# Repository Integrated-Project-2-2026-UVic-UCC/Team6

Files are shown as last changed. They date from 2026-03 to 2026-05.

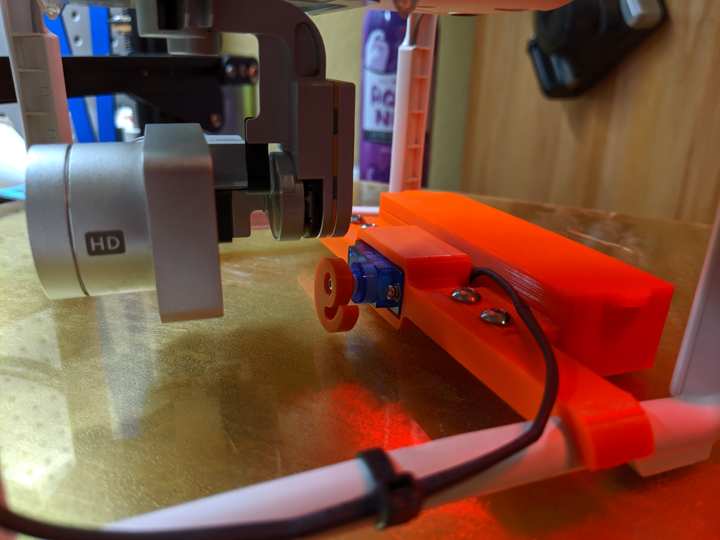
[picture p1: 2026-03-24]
Mechanical Components/Internet designs/IMG_20191102_212928.jpg

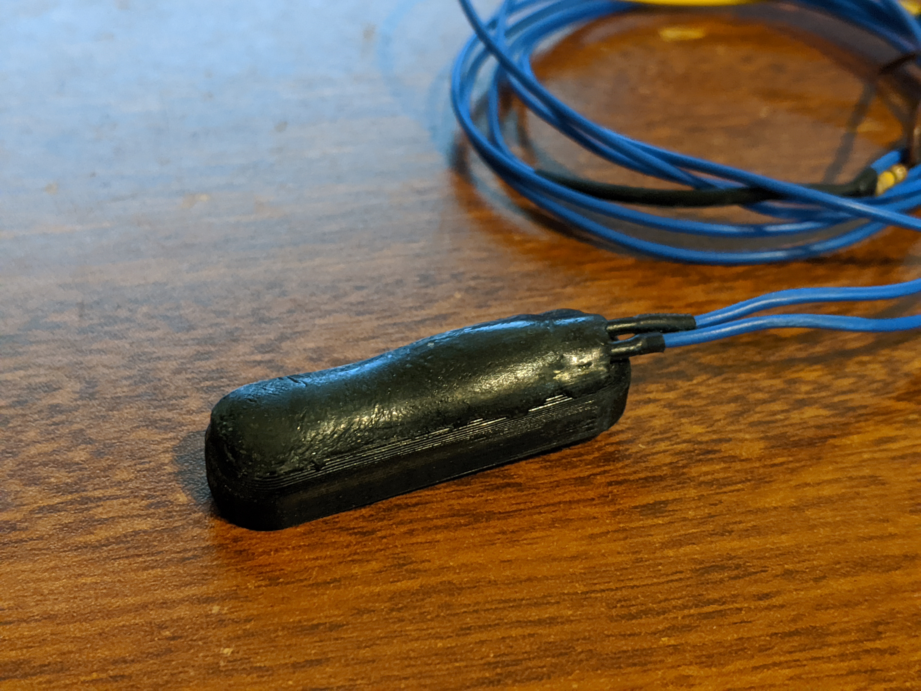
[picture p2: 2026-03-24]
Mechanical Components/Internet designs/IMG_20191102_212803.jpg

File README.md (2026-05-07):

## 1. Project Overview
This project focuses on the design, development, and integration of a remote-controlled attachable hook and pulley system for drones. The primary application is to facilitate automated and safe cable routing in environments where manual deployment is hazardous, inefficient, or physically restricted.

## 2. Objectives
The project is driven by a clear set of technical and operational goals:

### 2.1 Main Objective
To design and assemble a fully functional, remote-controlled hook attachment for drone-assisted cable deployment.

### 2.2 Specific Objectives
* **Pulley System:** Develop a reliable mechanism for cable management and tension control.
* **Safety Features:** Integrate hardware and software failsafes to ensure secure operations.
* **RF Communication:** Establish a robust Radio Frequency link for long-range control.
* **Validation:** Conduct rigorous testing to optimize performance and payload stability.

## 3. Team Organization and Methodology
The project follows a structured multidisciplinary model managed under the Scrum Framework.

### 3.1 Roles and Responsibilities
* **Project Leader:** Jan Font
* **Mechanical Manager:** Martí Alsina
* **Electrical Manager:** Oriol Bonet
* **Software Manager:** Xavier Vilalta

### 3.2 Professional Values (Scrum)
Our team operates under the core values of Courage to face technical challenges, Focus on sprint goals, Commitment to the project's success, Respect for individual expertise, and Openness regarding development obstacles.

## 4. Technical Architecture and Progress
The system is divided into three fundamental engineering pillars. Below is the progress achieved to date:

### 4.1 Mechanical tasks
* **Claw and Pulley Design:** Developed functional 3D designs for the mechanical gripping system.
* **Prototyping & Assembly:** Successful manufacturing and assembly of the first fully operational physical prototype.
* **Component Housings (Current Task):** Currently redesigning a larger protective enclosure (housing) to better accommodate all onboard drone electronics. Additionally, a dedicated, ergonomic casing for the remote control is being developed.

### 4.2 Electrical and Software tasks
* **RF Setup:** Established a stable communication link between the Transmitter (Command) and the Receiver.
* **System Logic:** Implementation of the electrical diagram, managing 5V output controls for motor drivers.
* **Power Management:** Integration of the battery and receiver units within the system logic.
* **Software Finalization:** The final control software (including motor control, safety limits, and communication protocols) is fully integrated and operational.

## 5. Project Roadmap and Current Status
The project has successfully transitioned into the real-world testing and iterative improvement phase. The first full prototype has been assembled and successfully flight-tested with the drone, with all systems functioning correctly. The current focus is on upgrading the physical enclosures for both the drone module and the remote control.

### 5.1 Achievements to Date
* Successful assembly of the first functional prototype.
* **Successful real-world flight testing with the drone**, confirming system reliability, payload stability, and the correct operation of all mechanical and electrical features.
* Final software logic is highly advanced and fully operational.
* Validation of the electrical control circuit and safety mechanisms.

### 5.2 Challenges Addressed (Job Stoppers)
* **LoRa Modules:** Overcame initial problems regarding establishing stable communication with the modules.
* **Procurement:** Managed minor delays in the component supply chain.

### 5.3 Next Steps
* Finalize and manufacture the redesigned, larger housing for the drone accessory to ensure an optimal and secure fit for all electronic components.
* Design, 3D print, and assemble the custom casing for the remote control.
* Identify final performance metrics and apply continuous technical improvements based on the recent flight testing feedback.

## 6. References
* Madsen, M. (2018). *DJI Phantom 3 – Payload Dropper v2*.
* Drone Sky Hook. *Dual Release and Drop PLUS for DJI Phantom 3*.
* 3Deddy. (2019). *DJI Phantom 3 – Payload Dropper*.

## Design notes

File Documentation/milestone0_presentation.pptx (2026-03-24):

## Milestone 0: Presentation

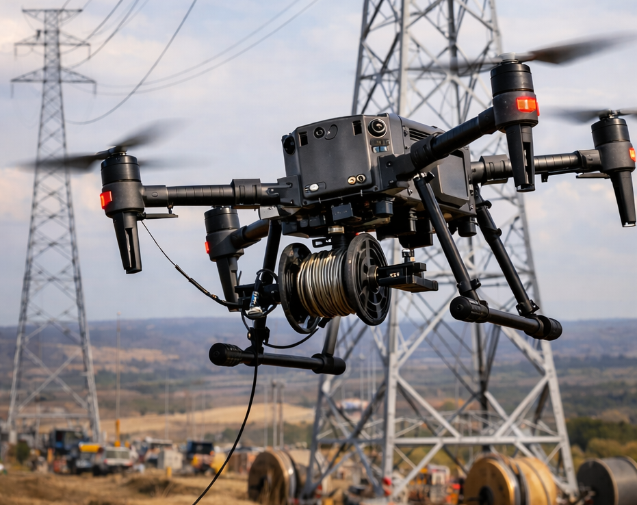
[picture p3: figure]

Oriol Bonet, Martí Alsina, Xavier Vilalta and Jan Font
Integrated Project II
Universitat de Vic

## PROJECT PROPOSAL

- Attachable hook for a drone
- Cable Routing
- Remote controlled

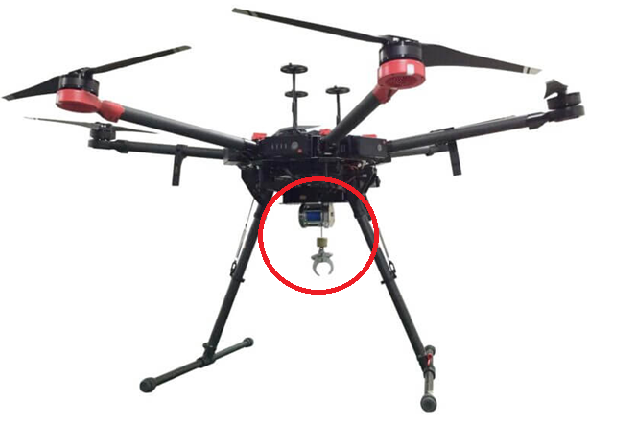
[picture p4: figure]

## OBJECTIVES

- Main objective
  - Assembly of a remote-controlled hook attachment
- Specific objectives
  - Pulley system
  - Safety features

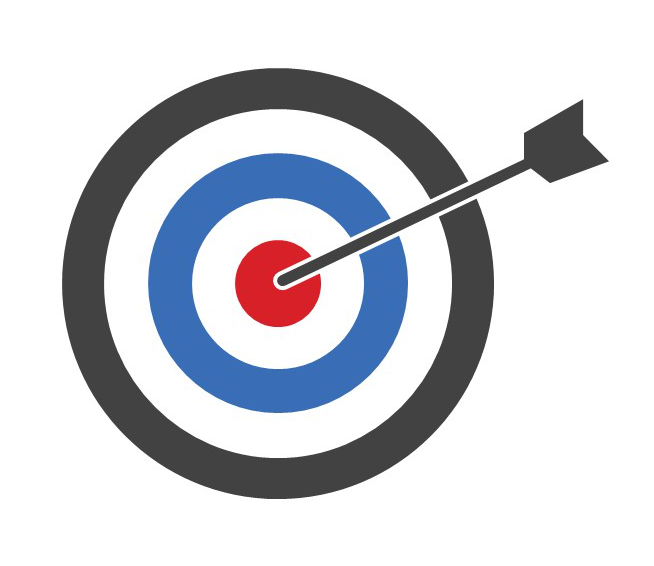
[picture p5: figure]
Simple Objective Slide Template for PowerPoint

## TEAM ORGANITZATION

- Project leader → Jan Font
- Mechanical manager → Martí Alsina
- Electrical manager → Oriol Bonet
- Software manager → Xavier Vilalta

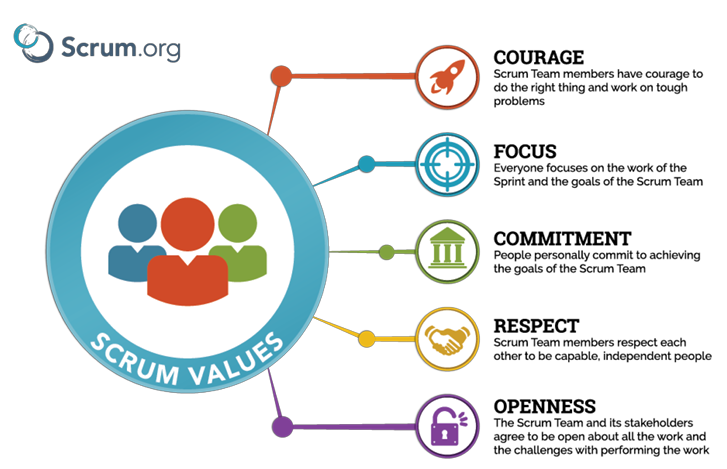
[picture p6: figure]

## MANAGEMENT PLANNING

Project leader
Mechanical manager
Electrical manager
Software Manager
All members

- Weekly review
- Sprint Planning / Sprint Review

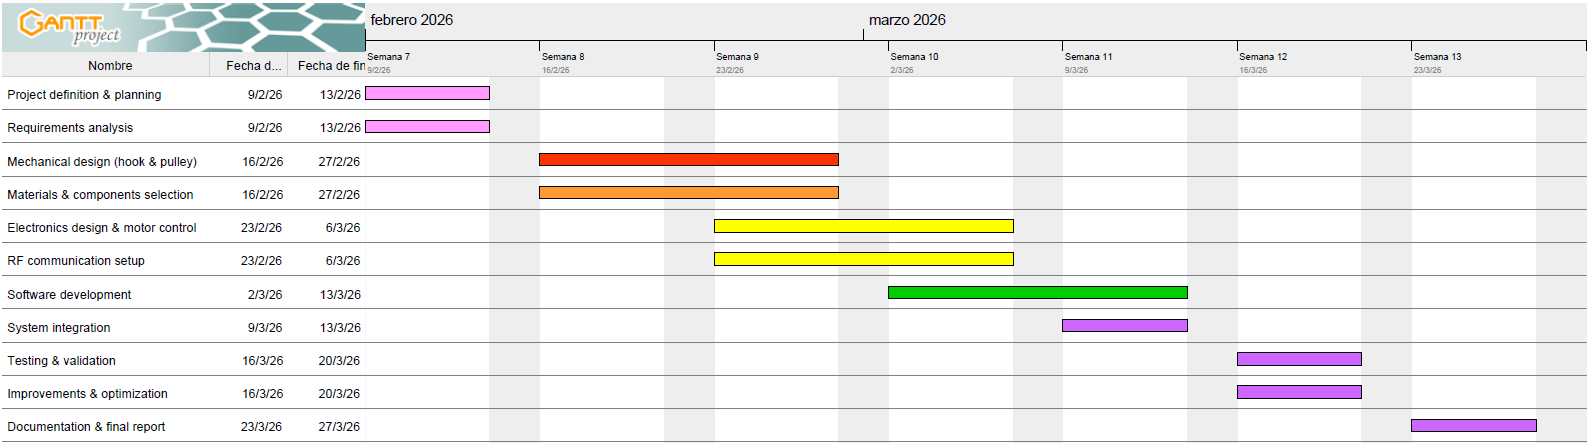
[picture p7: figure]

## WEBSITE

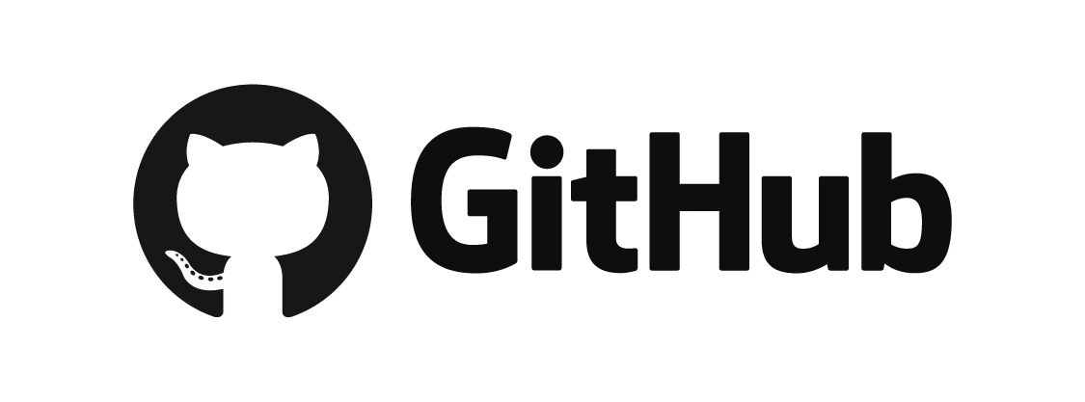
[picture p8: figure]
Unlocking the Power of GitHub: A Comprehensive Guide for Developers and Teams

- https://github.com/Integrated-Project-2-2026-UVic-UCC/Team6

## REFERENCES

- Madsen, M. (2018). DJI Phantom 3 – Payload Dropper v2. https://www.thingiverse.com/thing:2913421
- Drone Sky Hook. (n.d.). Dual Release and Drop PLUS for DJI Phantom 3. https://www.droneskyhook.com/product-page/Dual-Release-and-Drop-PLUS-for-DJI-Phantom-3
- 3Deddy. (2019). DJI Phantom 3 – Payload Dropper. https://www.thingiverse.com/thing:3953342

## Thank you for your attention!

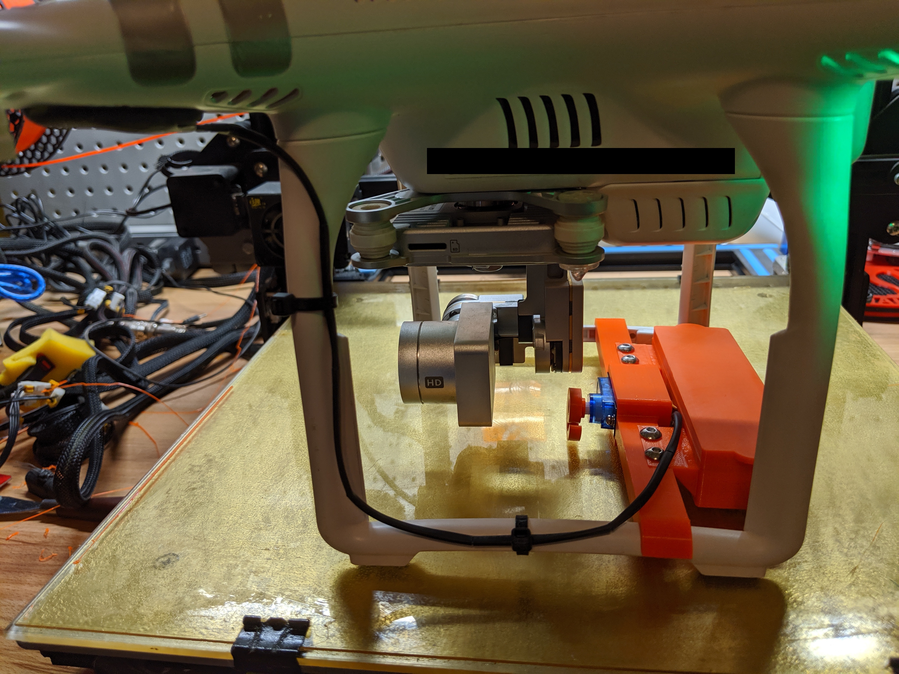
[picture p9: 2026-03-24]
Mechanical Components/Internet designs/Light_Cover.png

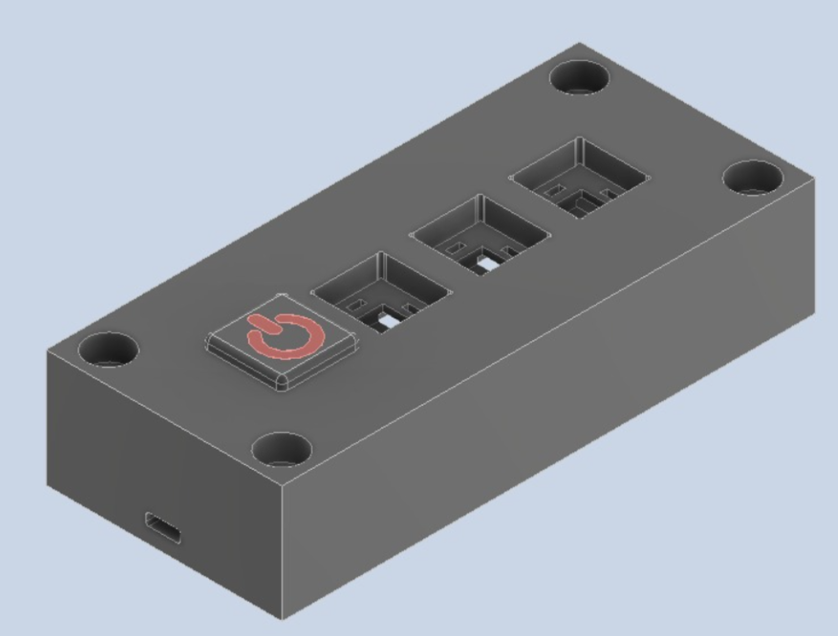
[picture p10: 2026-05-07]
Mechanical Components/Self made designs/Remote/Captura de pantalla 2026-05-07 155647.png

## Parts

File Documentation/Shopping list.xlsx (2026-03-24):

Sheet: Project Specifications
Micro Geared Motor
Angular Velocity [n] (rpm) | 35 | rpm
Angular Velocity [w] (rad/s) | 3.67 | rad/s
Nominal Power [W] | 0.25 | W
Roll radium r] | 5 | mm
Fmàx motor [F](N) | 13.64185227 | N
Max load [m](Kg) | 1.390606755 | Kg
Linial Velocity [v] | 0.01832595715 | m/s

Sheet: Shoping List
PRELIMINAR ORDER LIST
Team: | Group 6: Pulling cables
NAME | QUANTITY | LINK | PROVIDER | UNIT PRICE [€] | FINAL PRICE [€] | CURRENT COST [€] | AVAILABLE BUDGET [€]
Spiral cable | 1 | Cable (https://www.amazon.es/Espiral-Extensi%C3%B3n-Remolque-N%C3%BAcleos-Poliuretano/dp/B0BQGCTNV5) | Amazon | 32 € | 32 € | 207.37 € | 92.63 €
Batery | 1 | Batery (https://www.amazon.es/Recargable-4-8V-Juguetes-veh%C3%ADculos-Todoterreno/dp/B07Y9S5T6Z) | Amazon | 17 € | 17 €
Micro geared motor | 1 | Motor (https://www.amazon.es/Fasizi-35RPM-Metal-Motor-GA12-N20/dp/B09Z297R57) | Amazon | 10.99 € | 10.99
Fishing line | 1 | String (https://www.amazon.es/metros-transparente-monofilamento-alambre-tensi%C3%B3n/dp/B0BG2P8C16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) | Amazon | 5 € | 5
Magnetic sensor | 1 | Magnetic sensor (https://www.amazon.es/Interruptor-magn%C3%A9tico-Cilindro-neum%C3%A1tico-interruptor/dp/B08T6MTFHJ) | Amazon | 6.30 € | 6.3
Servomotor | 1 | Servo (https://www.amazon.es/Fasizi-unids-engranaje-anal%C3%B3gico-helic%C3%B3ptero/dp/B09Z28X9RL) | Amazon | 15.99 € | 15.99
Switch | 1 | Switch (https://www.amazon.es/SODIAL-250V-SPST-Interruptor-Basculante/dp/B00F4MG7HY) | Amazon | 3 € | 3
LoRa v3 | 1 | LoRa (https://www.amazon.es/Diymore-SX1262-Bluetooth-M%C3%B3dulos-Desarrollo/dp/B0DMDRY97S) | Amazon | 42.74 € | 42.74
Zip tie | 1 | Zip ties (https://www.amazon.es/AiQInu-Unidades-Bridas-Plastico-Peque%C3%B1as%EF%BC%8CBridas/dp/B0CSFKVPKQ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) | Amazon | 5.78 € | 5.78
Load sensor | 1 | Load sensor (https://www.amazon.es/dp/B0FPFWW4FL?aref=dMY6anLfPK&sp_csd=d2lkZ2V0TmFtZT1zcF9kZXRhaWw) | Amazon | 5.47 € | 5.47
Push buttons | 1 | Push buttons (https://www.amazon.es/DAOKAI-interruptor-moment%C3%A1neo-componentes-electr%C3%B3nicos/dp/B09WVFHMSV) | Amazon | 6.33 € | 6.33 €
LED lights | 1 | LED lights (https://www.amazon.es/Super-brillante-LEDs-Blanco-6000K/dp/B0784TDHVW) | Amazon | 7.65 € | 7.65 €
3D print wire | 1 | Print wire (https://www.amazon.es/ELEGOO-Filamento-Impresora-Dimensional-Impresoras/dp/B0F3BX78YW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) | Amazon | 13.21 | 13.21 €
Fuse Relay | 1 | https://www.amazon.es/TOOHUI-Soporte-Portafusibles-Standard-Impermeable/dp/B07KPKND2Q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 | Amazon | 12.98 | 12.98 €
Fuse Holder | 1 | https://www.amazon.es/AiQInu-Fusibles-12v-32v-Mediano-Autom%C3%B3vil/dp/B0F4CQXXV4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 | Amazon | 14.99 | 14.99 €
Relay | 1 | Relay (https://www.amazon.es/KY-019-disparador-Arduino-Raspberry-arduino/dp/B0CT39JT4P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) | Amazon | 7.94 | 7.94 €

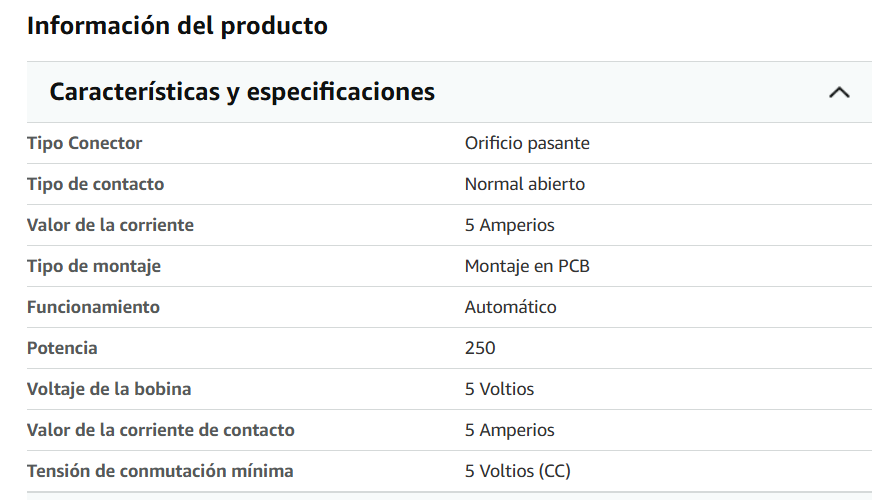
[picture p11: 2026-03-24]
Electronic Components/relay.png

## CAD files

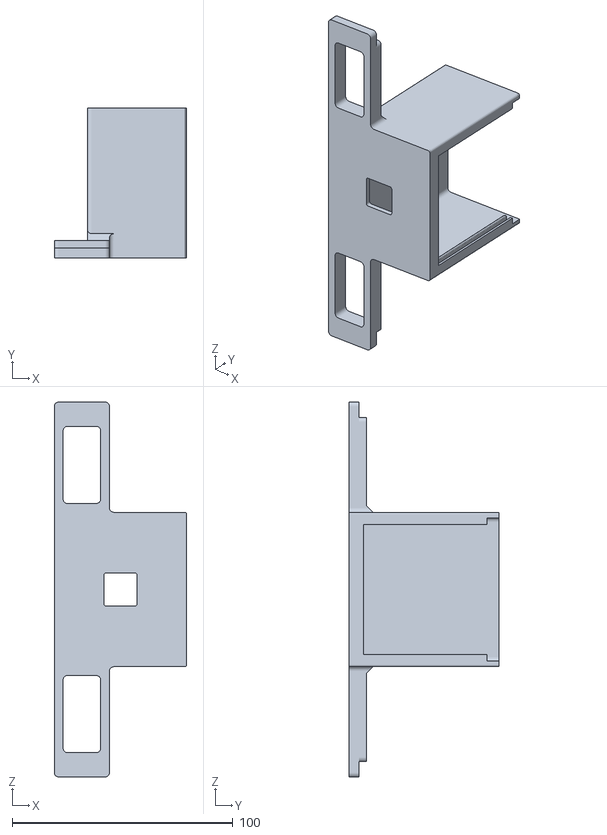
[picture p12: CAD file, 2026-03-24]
Mechanical Components/Self made designs/Components housing/Caixa_v2.stl
60.0 x 68.0 x 170.0

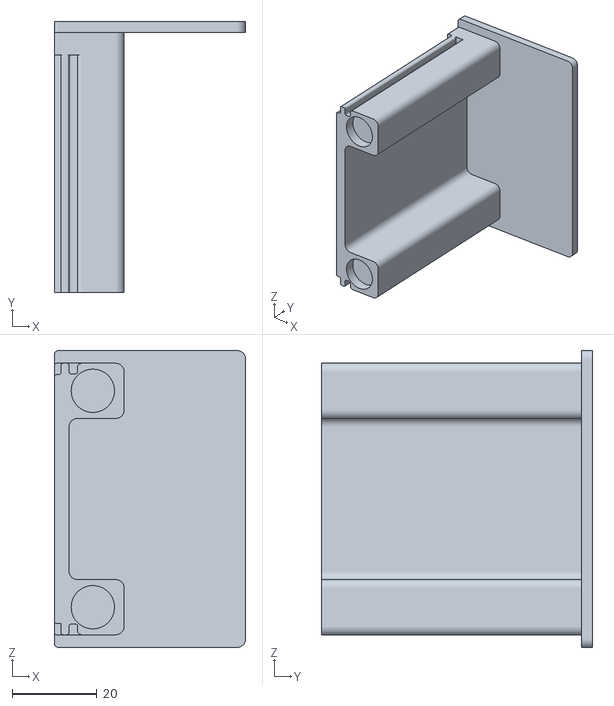
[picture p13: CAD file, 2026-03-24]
Mechanical Components/Self made designs/Components housing/tapa caixa.stl
45.1 x 63.8 x 70.0

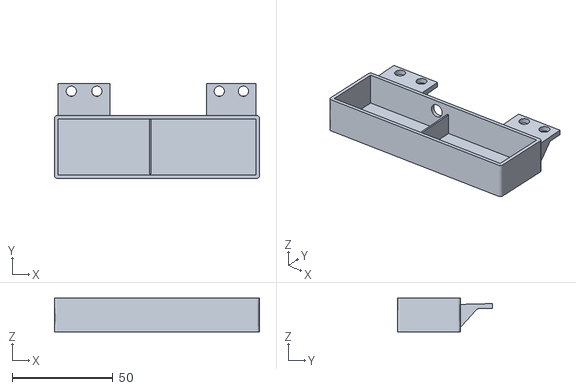
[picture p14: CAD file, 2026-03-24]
Mechanical Components/Internet designs/Light_Cover.stl
101.8 x 47.1 x 16.8

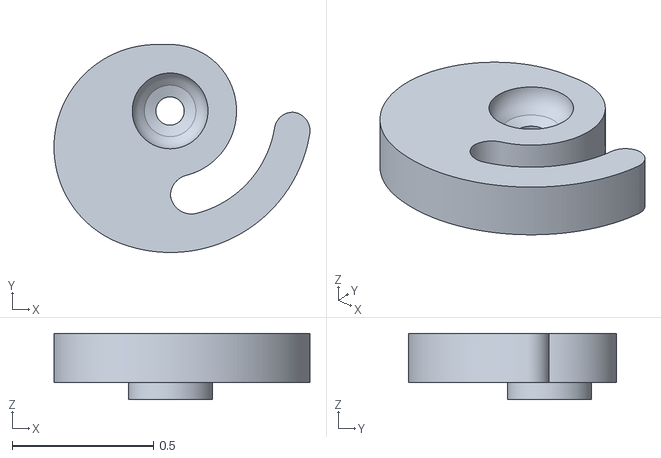
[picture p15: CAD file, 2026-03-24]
Mechanical Components/Internet designs/LOAD_BAR.stl
0.907 x 0.737 x 0.235

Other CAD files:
Mechanical Components/Internet designs/Servo_Connector_Gear.stl
Mechanical Components/Internet designs/MicroMotor_mount.STL
Mechanical Components/Internet designs/Base.stl
Mechanical Components/Internet designs/Connector_Gear.stl
Mechanical Components/Internet designs/Micro_gear01.STL
Mechanical Components/Internet designs/MicroMotor_mount_with_base.STL
Mechanical Components/Internet designs/Claw.stl
Mechanical Components/Internet designs/Micro_gear02.STL
Mechanical Components/Internet designs/Connector.stl

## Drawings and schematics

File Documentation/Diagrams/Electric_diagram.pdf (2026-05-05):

A1

-S3

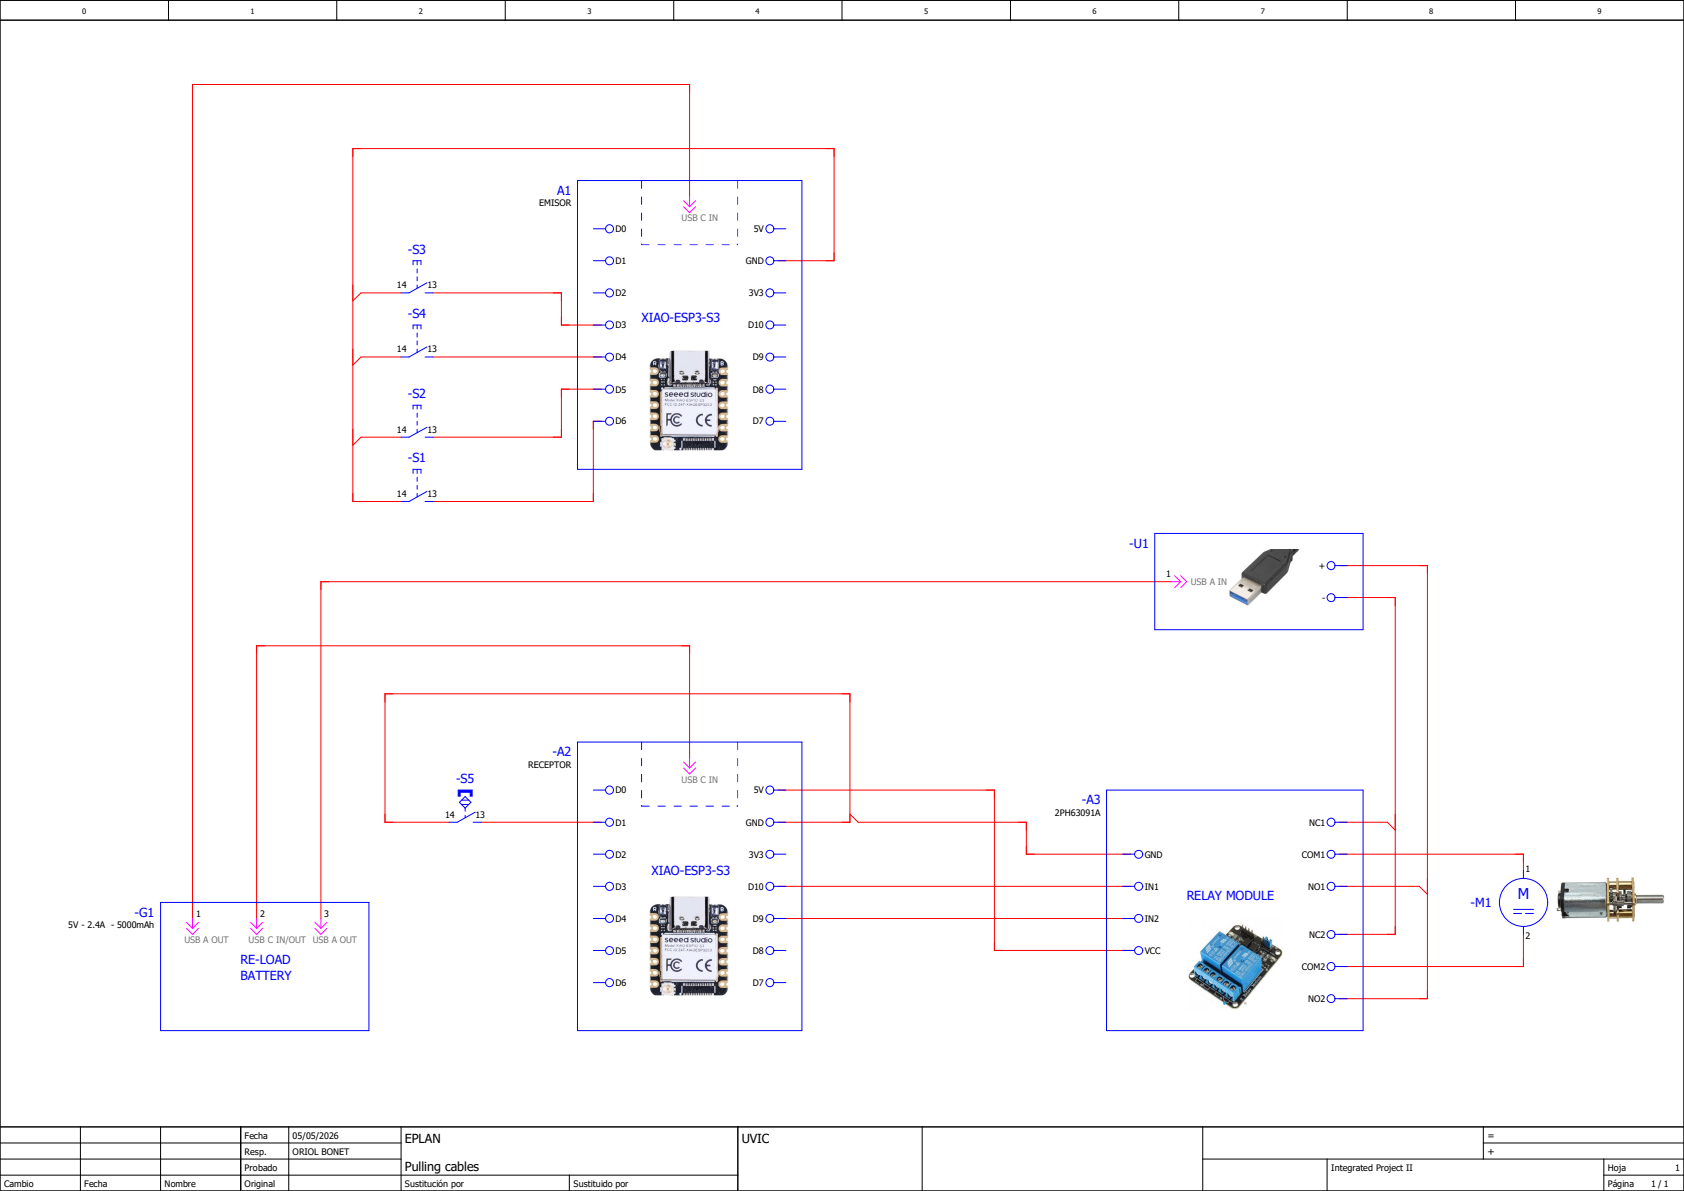
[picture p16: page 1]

Fecha | 05/05/2026 | EPLAN Pulling cables | UVIC | =
Resp. | ORIOL BONET | | | +
Probado | | | | Integrated Project II | Hoja 1

Cambio | Fecha | Nombre | Original | | Sustitución por | Sustituido por | | | Página 1 / 1

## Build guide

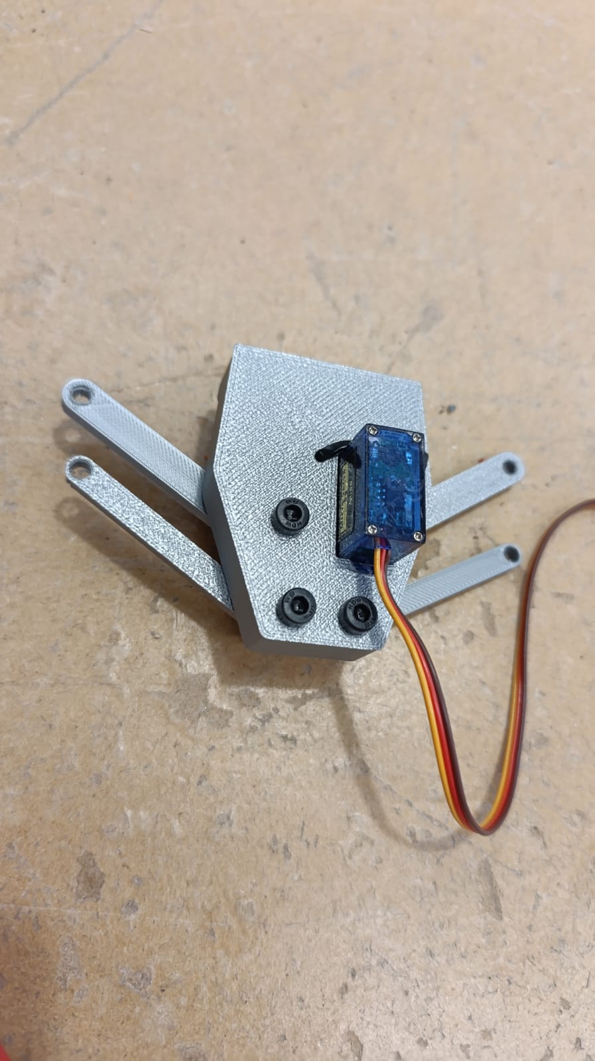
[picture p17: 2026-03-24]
Mechanical Components/3d printings/WhatsApp Image 2026-03-24 at 18.41.51.jpeg

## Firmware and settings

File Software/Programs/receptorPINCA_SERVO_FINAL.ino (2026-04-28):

#include <esp_now.h>
#include <WiFi.h>
#include <ESP32Servo.h>

Servo pincaServo;
const int pinServo = 1; 

const int releA = 9;  // D10 (Accionat per Botó 1 -> PUJAR)
const int releB = 8;  // D9  (Accionat per Botó 2 -> BAIXAR)
const int ledObert = 7;  
const int ledTancat = 44;

// Pin per al Sensor Magnètic de seguretat
const int pinSensor = 2; // Pin D1 de la XIAO

typedef struct {
  bool motorA;
  bool motorB;
  bool pinca;
} struct_message;

struct_message dadesRebudes;

// Variables per memoritzar les ordres de l'emissor
bool ordreMotorA = false;
bool ordreMotorB = false;

// --- TRUC MULTIVERSION ---
#if ESP_ARDUINO_VERSION >= ESP_ARDUINO_VERSION_VAL(3, 0, 0)
void alRebre(const esp_now_recv_info_t *info, const uint8_t *data, int len) {
#else
void alRebre(const uint8_t *mac, const uint8_t *data, int len) {
#endif
// -------------------------

  memcpy(&dadesRebudes, data, sizeof(dadesRebudes));

  // Guardem el que ens demana l'emissor
  ordreMotorA = dadesRebudes.motorA;
  ordreMotorB = dadesRebudes.motorB;

  // Lògica de la pinça
  if (dadesRebudes.pinca == true) {
    pincaServo.write(70); 
    digitalWrite(ledObert, HIGH);
    digitalWrite(ledTancat, LOW);
  } else {
    pincaServo.write(0);
    digitalWrite(ledObert, LOW);
    digitalWrite(ledTancat, HIGH);
  }
}

void setup() {
  Serial.begin(115200);
  
  pinMode(releA, OUTPUT);
  pinMode(releB, OUTPUT);
  pinMode(ledObert, OUTPUT);
  pinMode(ledTancat, OUTPUT);
  
  // Configurem el sensor amb la resistència pull-up interna
  pinMode(pinSensor, INPUT_PULLUP);

  digitalWrite(releA, LOW);
  digitalWrite(releB, LOW);

  ESP32PWM::allocateTimer(0);
  pincaServo.setPeriodHertz(50); 
  pincaServo.attach(pinServo, 500, 2400); 

  WiFi.mode(WIFI_STA);
  WiFi.disconnect();
  
  if (esp_now_init() != ESP_OK) return;
  
  esp_now_register_recv_cb(alRebre);
}

void loop() {
  // LLEGIM EL SENSOR: Si detecta l'imant, el pin baixa a LOW
  bool imantDetectat = (digitalRead(pinSensor) == LOW);

  if (imantDetectat) {
    // FINAL DE CARRERA ACTIVAT (Límit de pujada)
    // Forcem el Relé A a LOW (no pot pujar més), però deixem actuar el Relé B (pot baixar).
    digitalWrite(releA, LOW);
    digitalWrite(releB, ordreMotorB ? HIGH : LOW);
  } else {
    // FUNCIONAMENT NORMAL (Cap obstacle)
    // Apliquem les ordres que arriben de l'emissor per a tots dos sentits.
    digitalWrite(releA, ordreMotorA ? HIGH : LOW);
    digitalWrite(releB, ordreMotorB ? HIGH : LOW);
  }
  
  delay(10); // Petita pausa per donar estabilitat al microcontrolador
}

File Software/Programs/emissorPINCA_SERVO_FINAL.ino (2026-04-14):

#include <esp_now.h>
#include <WiFi.h>

uint8_t broadcastAddress[] = {0x8C, 0xBF, 0xEA, 0x8E, 0xDD, 0x6C}; 

const int pinB1 = 4;
const int pinB2 = 5;
const int pinB3 = 6;
const int pinB4 = 43;

typedef struct {
  bool motorA;
  bool motorB;
  bool pinca;
} struct_message;

struct_message dades;
bool estatPinca = false;
unsigned long ultimDebounce = 0;

void setup() {
  Serial.begin(115200);
  pinMode(pinB1, INPUT_PULLUP);
  pinMode(pinB2, INPUT_PULLUP);
  pinMode(pinB3, INPUT_PULLUP);
  pinMode(pinB4, INPUT_PULLUP);
  
  WiFi.mode(WIFI_STA);
  WiFi.disconnect();

  if (esp_now_init() != ESP_OK) return;
  
  esp_now_peer_info_t peerInfo = {};
  memcpy(peerInfo.peer_addr, broadcastAddress, 6);
  peerInfo.channel = 0;
  peerInfo.encrypt = false;
  esp_now_add_peer(&peerInfo);
}

void loop() {
  bool estatB1 = (digitalRead(pinB1) == LOW);
  bool estatB2 = (digitalRead(pinB2) == LOW);

  if (digitalRead(pinB3) == LOW && (millis() - ultimDebounce > 250)) {
    estatPinca = true;
    ultimDebounce = millis();
  }
  
  if (digitalRead(pinB4) == LOW && (millis() - ultimDebounce > 250)) {
    estatPinca = false;
    ultimDebounce = millis();
  }

  if (dades.motorA != estatB1 || dades.motorB != estatB2 || dades.pinca != estatPinca) {
    dades.motorA = estatB1;
    dades.motorB = estatB2;
    dades.pinca = estatPinca;
    esp_now_send(broadcastAddress, (uint8_t *) &dades, sizeof(dades));
    
    Serial.printf("Enviat -> MotorA:%d | MotorB:%d | Pinca:%d\n", dades.motorA, dades.motorB, dades.pinca);
  }
  delay(10);
}
